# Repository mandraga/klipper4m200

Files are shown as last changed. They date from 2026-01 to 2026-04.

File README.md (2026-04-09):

# klipper4m200

A replacement firmare for the Zortrax M200+ 3D printer.

This firmware is based on Debian/Armbian and allows to install klipper on the m200+.
There is no comming back once the microcontroller is flashed.

# Building steps

Update the submodules, or get them separately.
* Armbian build
* u-boot
* sunxi-tools

## Access the internal single board computer

You need:
* a serial port on the UART0 J5 connector for the u-boot and Linux serial console.
* a special USB-A to USB-A cable with no 5V connexion to be able to use the FEL mode.

At boot, press '2' on the serial console, it will start in FEL mode.
You should see this on "dmesg -w":
```
ID 1f3a:efe8 Allwinner Technology sunxi SoC OTG connector in FEL/flashing mode
```
Then, using sunxi-tools, you can upload a uboot image like this:
```
sunxi-tools$ sudo ./sunxi-fel uboot ../u-boot/u-boot-sunxi-with-spl.bin
```
It starts uboot and you can browse files and dump data.

Then you can use this uboot prompt to load the dtb and the kernel, then boot Armbian from the usb stick.

Once in Linux, you can:
- dump the original disk image on the usb stick.
- dump the vendor u-boot env
- write your u-boot-env
- write u-boot-dtb.bin to the FAT16 partition

## Download the image

Compile u-boot with build_m200.sh from the bootstage folder in this repo, run it in the u-boot fork repo.
Create an Armbian full image using the lime-A33 board using the armbian_build repo.
DD it on /dev/sdx2 where sdx is your usb stick (or edit uboot command to use sdx1 instead).
Do not forget to include linux headers and to enable the touchscreen (see linux.md).
In armbian_build:
```
./compile.sh INSTALL_HEADERS=yes
```

## At first boot from FEL mode

Look at usb.md or progress.md to see how to load the kernel from u-boot.

Install the new u-boot env and mainline uboot binary on the emmc such as to automaticly boot from the USB drive.
The original emmc is not that much altered, only the env. You can resore it with a backup file or in vendor u-boot console.

### Get the network

* On version 2.1, Linux should detect the ethernet usb adapter on the USB port.
  Version 2.1 has two usb ports.
* On version 1.1, the USB0 trace must be cut and a posrt soldered to boot from USB. You need to connect some ethernet 
adapter to an usb hub.
  Version 1.1 has only one USB port on the front.

Then connect your printer to the network.

### Install klipper

Follow this tutorial
https://travis90x.altervista.org/armbian-first-boot-and-install-klipper/

```
git clone https://github.com/dw-0/kiauh.git
./kiauh/kiauh.sh
```
It will install everything klipper related and build the firmware.

### Flash the microcontroller and start Klipper

See the Readme in the MCU folder, you need an ST-Link programmer to mass erase the chip.

## Klipper config

rpanfili has already configured klipper for zortrax M200 but for an SK200 MCU board.
However the geometry and a lot of stock parameters are already in his configuration.

Zortrax has published a Marlin port for the M200.
By looking at the commits, and the work done in the zmxxxp-re repository, I could find the MCU pinouts in "pins_ZORTRAX_M200.h" to configure the klipper MCU firmware.
Be carefull whith the X, Y axis stops, they are not the same depending on verison 1.1 or 2.2.

The configuration in this repo is the rpanfili one, modified for the Zortrax MCU board instead of the SK1.4.

## Calibration and tuning

https://ellis3dp.com/Print-Tuning-Guide/
https://github.com/OrcaSlicer/OrcaSlicer/wiki/Calibration

The ZABS spec
https://cf.zortrax.com/wp-content/uploads/2020/09/Z-ABS_2_Technical_Data_Sheet_eng.pdf

PID tuning at different fan speeds and in GCODE:
https://www.youtube.com/watch?v=USvg6D0cXE4

## Start printing

If everything went fine, you can connect to Mainsail or Fluid web interfaces copy the klipper configuration and start configuring the bed level.
Then, because it is klipper, you must run calibration towers with your filaments and tweak orcaslicer prior to begin printing. That's what's lost in the process but you have control and can use any filament.

## About

This work lasted from october 2025 to April 2026 and was much more difficult than planed, given that the device tree of this thing is really complex, the EMMC is really touchy, and the screen had no driver.
The boot process led to 4 bricks, and needed resoldering a new programmed EMMC to save the boards.
Since then, I tryed to port an ezeetab 96Q10 A-33 Andorid tablet to linux and it was quicker (a week) and also helped to progress on this project.

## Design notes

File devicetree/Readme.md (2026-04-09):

# Mainline linux device tree and u-boot

For the device tree, see git@github.com:mandraga/u-boot.git on the branch zortrax-m200plus.

# Original fex file from the vendor bootloader stage 2

zortraxm200_1.fex is the disassembled version of the printer device description.
Not every voltage regulator in there is found on the board after boot but it was mandatory information to create the linux mainline device tree.

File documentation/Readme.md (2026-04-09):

## Youtube on the open source  Zortrax Marlin port

https://www.youtube.com/watch?v=6i0SUXQyLa4

## Klipper

https://www.youtube.com/watch?v=er7q-CJL1lc
https://mmone.github.io/klipper/Installation.html
https://www.klipper3d.org/Bootloaders.html#stm32f103-micro-controllers-blue-pill-devices
https://github.com/Klipper3d/klipper
https://github.com/Arksine/katapult
https://github.com/dw-0/kiauh

## MarlinZortrax

https://github.com/Zortrax3D/MarlinZortraxM200

## eevblog topic on klipper for zortrax

https://www.eevblog.com/forum/3d-printing/hack-zortrax-driver-board-port-klipper/

https://github.com/zharijs/zmxxxp-re

## Zortrax is cooked but still alive

https://forum.zortrax.com/t/m200-m300-marlin-2-1-x-firmware-release/14264/38

### Total conversion

https://github.com/rpanfili/sk200

## A33 sunxi ressources

### Machine alike

https://linux-sunxi.org/Sinlinx_SinA33
Nearly the same, when looked from a distance.

## Zortrax Machine

* A33
* 1GB DDR3
* 8GB EMMC
* 2 usb ports
* UART0 J5 console port (molex)
* HOME/FEL mode button (only for android)

Pinout in A33-core3.pdf
Adafruit SSDIO breakout board:
https://www.adafruit.com/product/4682

### Connector

C'est du Molex.

### Flash methods

https://docs.u-boot.org/en/latest/board/allwinner/sunxi.html

### FEL flash method
https://linux-sunxi.org/FEL

### UBoot
https://github.com/u-boot/u-boot/blob/master/doc/board/allwinner/sunxi.rst

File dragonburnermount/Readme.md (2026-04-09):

# Adapting a Dragon burner head to the zortrax m200

## Why?

* Your heater element is broken or missing
* You want more up to date tech
* You bough a Zortrax M200 or M300 without heating element.

## How?

* Print an adapter
  Use the dragon burner configurator https://dragonburner.voron.zip/DragonBurnerConfig/#/
* Chose your heat element
* Solder the fan cables to extend them (maybe you can reuse the heater element fan)
* Change the thermistor for a themocouple (like 1188-TC-K-TYPE-ND form Olimex)

## What heat element?

I chose a Rapido and a TZ-V6-2. But you have to solder things and it is anoying.
The best choice would be a Phaetus Dragon hotend because you do not change the heating elements
nor the thermocouple. And with a bit of luck with the fans cable length, you do not have to solder.

### Phaetus Rapido

And download the main body and the rapido adapter.
Instead of an extruder mount, print dragonburnermountonM200_B.stl
You need 35mm 5mm/6mm M3 screws (flat head for the 6mm long screw).
Replace the thermistor with a thermocouple.

### Triangle labs TZ-V6-2

This one is not really suported by the dragon burner project.
You need 35mm 5mm/6mm M3 screws (flat head for the 6mm long screw).
Replace the thermistor with a thermocouple.
Print the main fan body and this adapter:
https://www.printables.com/model/1292661-dragonburner-tz-v6-20-mount-with-v6-nozzle
Add washers on the support because the heater wobbles.
Change the nozzle to a V6 because the default nozzle is not made for that mount.
It will be at blower level and won't work.

### Dragon hotend

Not tested, but should be the simplest. Using the original heater and thermocouple even if the wire are a bit short. It is the first choice for the Dragon burner and it is afordable.
You need 35mm or 5mm/6mm M3 screws (flat head for the 6mm long screw).

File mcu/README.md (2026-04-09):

## MCU compilation for the MCU board

The MCU is a STM32F103VC on the M200 and the stepper motor drivers are A4988.
Format LQFP100

STM32F103VC
Flash memory: 256KB
SRAM: 64 KB
Package: LQFP100

### From the Marlin port

```
#
# Zortrax M200/M300 (STM32F103VCT6)
#
[env:STM32F103VC_zortrax_m200]
extends                     = stm32_variant
board                       = genericSTM32F103VC
board_build.variant         = MARLIN_F103Vx
build_flags                 = ${stm32_variant.build_flags} -DDEBUG_LEVEL=0
monitor_speed               = 115200
board_build.offset          = 0x8000       (32768 bytes, 32K offset)
board_upload.offset_address = 0x08008000
```
However, their bootloader is undocumented and the data seems encrypted because firmware.bin does not contian arm code.
It can be replaced by Katapult, using the debug pins.

### Build the firmware

```
./kiauh/kiauh.sh
Select
 4) [Advanced] 
  1) [Build] 
```

And then select (Enable extra low-level configuration options):
Micro-controller Architecture: STM32
Processor model:               STM32F103
Bootloader at:                 8K for katapult, 32K if it was the zortrax bootloader (and it is not).
Communication interface:       USART2 on PA3 PA2
Frequency                      8Mhz

It will build the firmware.

### Configure

The firmware is generic, it needs a configuration file to assign the pins and other stuff.
The configuration can be deduced from the Zortrax Marlin port. See in "pins_ZORTRAX_M200.h".

The other part of the work for the printer configuration has been made by rpanfili in his sk200 retrofit.
He used an sk200 and he changed the stepper motors and mybe the extruder but the other parts are the same.

#### Serial communication

To connect serial user interface (OctoPrint or other using Raspberry PI or UART converter and PC) you can use debug header on the motherboard. You will need to solder connector by yourself.

Pinout of the **DEBUG** header described below:
-	NRST
-	**GND <--- connect to GND on host**
-	TMS/NC SWDIO
-	TCK/NC SWDCLK
-	**TX <--- connect to RX on host**
-	**RX <--- connect to TX on host**
-	BOOT0
-	VCC (marked on mainboard as 3.3V)

**Caution**: if you are going to use debugger (ST-Link), know that any attempt to read or write from/to flash memory will result in mass erase of the flash. It will erase the the bootloader and all the settings, including lifetimer, serial number and hardware version, as flash memory of chip is read out protection enabled at production! If that happens you won't be able to use official firmware anymore!

### Android board P3 Pins

Android side       MCU side

5V                 5V
GND                GND
GPIO               STM
ADOHC              MTS
LED                BOOT
GPIOS              GPIO
RST                RST
SLP
RX                 RX
TX                 TX

      MCU Pins                              Android pins
-------------------------------------------------------------------------------------------------
STM   is PD2 TIM3_ETR/UART5_RX/SDIO_CMD     gpio_pin_5 = port:PC01<1><default><default><0>  MISO
MTS   is PD1 OSC_OUT/FSMC_D3/CAN_TX         gpio_pin_6 = port:PC00<1><default><default><0>  MOSI
BOOT  is PD3 USART2_CTS                     gpio_pin_7 = port:PC02<1><default><default><1>  CLK
GPIO  is PD5 USART2_TX                      gpio_pin_8 = port:PC03<0><1><default><0>        CS
RESET is PD4 USART2_RTS                     gpio_pin_9 = port:PF01<1><default><default><0>  
SLP   is not connected                      gpio_pin_10 = port:PF00<1><default><default><0>
RX    is PA3 USART2_RX                      PB0
TX    is PA2 USART2_TX                      PB1

uart2_cts_rts_pb_pins: uart2-cts-rts-pb-pins {
    pins = "PB2", "PB3";
    function = "uart2";
};

## Debug connector:

RESET; VSS/GND; PA13;     PA14;        PA10;       PA9;      BOOT0; 3.3V
              JTMS-SWDIO  JTCK-SWCLK  USART1_RX  USART1_TX
                                           
                                           STLINK
1 3.3V (square pin)                     1 3.3V (square pin)    X
2 BOOT0                                 2 SWCLK                to 5
3 PA9      USART1_TX                    3 GND                  to 7
4 PA10     USART1_RX                    4 SWDIO                to 6
5 PA14     JTCK-SWCLK                   5 RESET                to 8
6 PA13     JTMS-SWDIO                   6 SWO                  X
7 VSS/GND
8 RESET

### Katapult configuration

Replacing the vendor bootloader with the katapult bootloader using the debug port.

To configure the Katapult bootloader. From the katapult repo: use the following `make menuconfig` options.

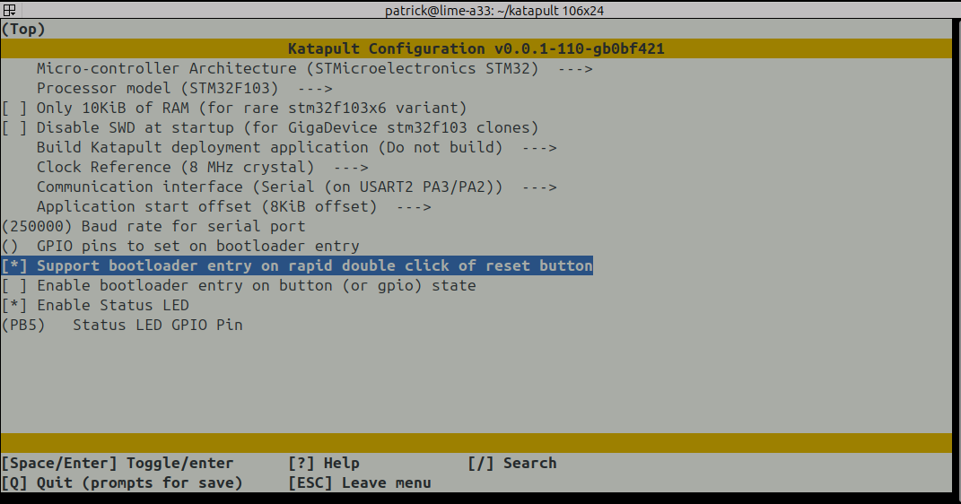
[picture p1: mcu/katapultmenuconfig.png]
Katapult Menuconfig


In the Katapult repo:
```
make menuconfig

Micro-controller architecture: STM32F13
No deployment application
Clock reference: 8Mhz crystal
Communicaiton iunterface: USART2 PA3/PA2
Application start offset 8KB offset.

make
```

It generates ./out/katapult.bin
That's what we flash as bootloader.
Using the Katapult's flashtool on the debug header. This erases the chip and there is no coming back to the Zortrax firmware and software suite.
The stock MCU is read protected, we must do a mass erase prior to flashing Katapult.
An uart is not enough, we need the SWDIO SWDCLK pins connected to a STLINK V2 system.

```
$ sudo apt update
$ sudo apt install stlink-tools openocd

# Unlock the chip with open ocd
# Start openocd
$ openocd -f interface/stlink.cfg -f target/stm32f1x.cfg

# In another console:
$ telnet localhost 4444
Trying 127.0.0.1...
Connected to localhost.
Escape character is '^]'.
Open On-Chip Debugger
> reset halt
[stm32f1x.cpu] halted due to debug-request, current mode: Thread 
xPSR: 0x01000000 pc: 0xfffffffe msp: 0xfffffffc
> stm32f1x unlock 0
device id = 0x10036414
STM32 flash size failed, probe inaccurate - assuming 512k flash
flash size = 512 KiB
stm32x unlocked.
INFO: a reset or power cycle is required for the new settings to take effect.

> shutdown
shutdown command invoked
Connection closed by foreign host.
```
Then reset the chip and use st-flash to finish the job.
```
$ st-info --probe

Found 1 stlink programmers
  version:    V2J16
  serial:     303030303030303030303031
  flash:      262144 (pagesize: 2048)
  sram:       65536
  chipid:     0x414
  dev-type:   F1xx_HD

$ st-flash erase
st-flash 1.8.0
2026-01-23T23:15:39 INFO common.c: F1xx_HD: 64 KiB SRAM, 24544 KiB flash in at least 2 KiB pages.
Mass erasing...
Mass erase completed successfully.

$ st-flash write ./out/katapult.bin 0x8000000

st-flash 1.8.0
2026-01-23T23:28:59 INFO common.c: F1xx_HD: 64 KiB SRAM, 256 KiB flash in at least 2 KiB pages.
file ./out/katapult.bin md5 checksum: 3f9582c8e129668f7be5ef1487634c7, stlink checksum: 0x0004b37d
2026-01-23T23:28:59 INFO common_flash.c: Attempting to write 3348 (0xd14) bytes to stm32 address: 134217728 (0x8000000)
-> Flash page at 0x8000800 erased (size: 0x800)
2026-01-23T23:28:59 INFO flash_loader.c: Starting Flash write for VL/F0/F3/F1_XL
2026-01-23T23:28:59 INFO flash_loader.c: Successfully loaded flash loader in sram
2026-01-23T23:28:59 INFO flash_loader.c: Clear DFSR
2026-01-23T23:28:59 INFO flash_loader.c: Clear CFSR
2026-01-23T23:28:59 INFO flash_loader.c: Clear HFSR
  2/2   pages written
2026-01-23T23:28:59 INFO common_flash.c: Starting verification of write complete
2026-01-23T23:28:59 INFO common_flash.c: Flash written and verified! jolly good!
```

STM32Programmer can also be used to the same goal.

### Flashing the klipper software

Now from the single board computer.

To configure the Klipper firmware, you can use the following `make menuconfig` options from the klipper repo. Refer to the image below for guidance:

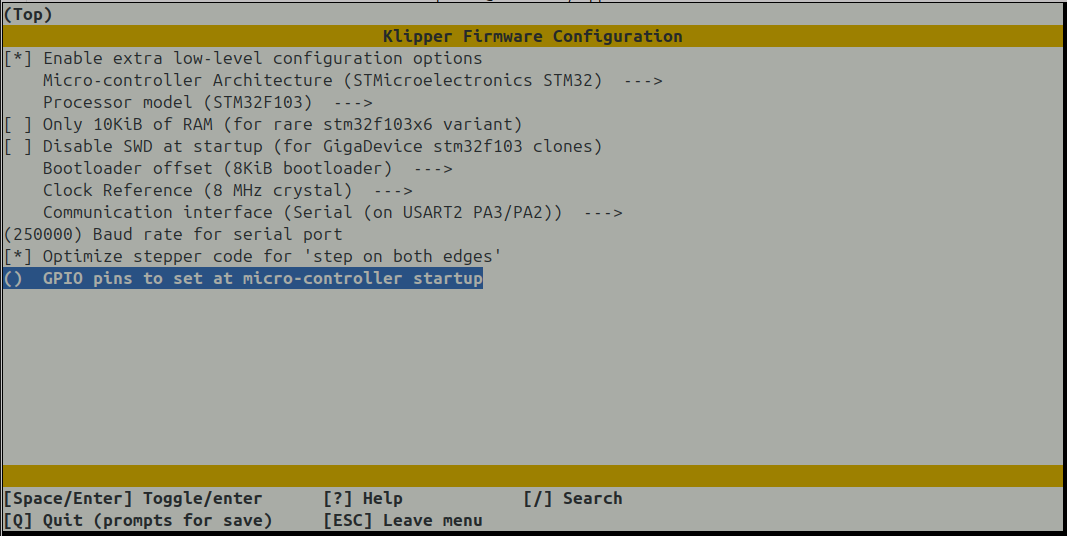
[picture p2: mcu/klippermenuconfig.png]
Klipper Menuconfig


Make sure to select the appropriate options for your setup.
```
make menuconfig
make

~$ sudo apt update
~$ sudo apt install python3-serial
~$ sudo service klipper stop
# Reset the device with the debug port
~$ sudo python3 ./katapult/scripts/flashtool.py -d /dev/ttyS2 -b 250000 -f ./klipper/out/klipper.bin
Connecting to Serial Device /dev/ttyS2, baud 250000
Detected Klipper binary version v0.13.0-464-g48f0b3ca, MCU: stm32f103xe
Attempting to connect to bootloader
Katapult Connected
Software Version: v0.0.1-110-gb0bf421
Protocol Version: 1.1.0
Block Size: 64 bytes
Application Start: 0x8002000
MCU type: stm32f103xe
Flashing '/home/patrick/klipper/out/klipper.bin'...

[##################################################]

Write complete: 19 pages
Verifying (block count = 581)...

[##################################################]

Verification Complete: SHA = 937D058BE91B1866070F106B6476898C47725810
Programming Complete
```

### Update the firmware using the bootloader

Once klipper installed with the STM32 programmer, we can update the firmware using the serial port.
If fuser of the Klipper serial port returns something, then stop the Klipper service.
```
fuser /dev/ttyS2
/dev/ttyS2:            946
sudo service klipper stop
# Reset the mcu board using the debug port
sudo python3 ./katapult/scripts/flashtool.py -d /dev/ttyS2 -b 250000 -f ./klipper/out/klipper.bin
sudo service klipper start
```

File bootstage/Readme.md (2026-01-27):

Find a compatible u-boot here: git@github.com:mandraga/u-boot.git
The device tree is in this repository.
It is also in the submodules.

The modified u-boot env replaces the stock env, it adds a one second wait to enter the u-boot console instead of zero, and chain loads u-boot mainline as default boot command.

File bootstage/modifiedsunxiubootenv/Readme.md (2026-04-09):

## Env to chainload u-boot

This env image for sunxi secondary loader chainloads u-boot from the FAT16 partition.
To install it from Armbian:

```
dd if=sunxi_env.img of=/dev/mmcblk2p5
```

And copy u-boot proper to mmcblk2p2:

```
cd /mnt/
mkdir -p /mnt/ext4disk
mkdir -p /mnt/fat16disk
mount /dev/sda1 ext4disk/
mount /dev/mmcblk2p2 fat16disk
cp ext4disk/u-boot-dtb.bin fat16disk/
sync
reboot
```

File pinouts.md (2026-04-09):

## P3 Single Board Computer to Micro Controller Unit

It goes through a level shifter, and the labels are obfuscated.

1  TX
2  RX
3  SLP
4  RST
5  GPIOS
6  LED
7  ADOHC
8  GPIO
9  GND
10 5V

## SDIO

The first SD card slots is not populated. 
SDIO_0 has no traces outside of the SOM board, SDIO_1 goes to an unpopulated SDWifi chip..
A test to use it with a card did not work.

## LED

Two onboard leds. Only the power led does something below the power button.
BTW the power button is more of a reset button.

## USB

Both usb are used.
USB1 on J4
USB0/OTG on P4

## Ethernet

On rev1 we have a soldered realtek ehternet chip. We cut it out in order to solder an usb hub.
On rev2 we have an USB2.0 Hub and the realtek ehternet chip is there. No need to cut or solder anything.

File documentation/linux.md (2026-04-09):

## Menuconfig the kernel compilation.

In the armbian image repository (https://github.com/armbian/build.git)

./compile.sh INSTALL_HEADERS=yes
and chose to show a menuconfig

Configure to use the lime A33 system.

## Touch screen information

https://forum.armbian.com/topic/7233-bananapi-pro-7-touchlcd-with-debian-buster-and-mainline-kernel-5xxxx/

## LCD information

The screen is a "MTF0397SWI-06"
IC: OTM8019A
Sunxi driver: sl698ph_720p
We also find the name hx8394d in the driver functions.
Himax HX8394 is the mainline driver name for hx8394d, looks like the sunxi driver, same command codes but different data sizes in the two drivers.

In the sl698ph_720p driver it takes hx8394d or otm1283 depending on the identification result.

On a boot parition, we find lcd.ko containing sl698ph_720p but also lp079x01.
lp079x01 is an LG display.
The driver has been compiled with debug information. "otm1283_initialization_setting" apears in the debug info.
So we have the driver source code, we need to adapt it to mainline linux.

We find lcd names: tft720x1280 vvx10f004b00 lp907qx starry768x1024

Acording to the debug info, the lcd module includes sl698ph_720p.c. However his initialisation data is not the same as in the public sunxi driver, it must be extracted from the module on the printer.

# Possible modern drivers to be used as "donor" structure

https://github.com/l33tnoob/tinno82_S5501/blob/master/mediatek/custom/common/kernel/lcm/otm1283a_hd720_dsi_vdo/otm1283a_hd720_dsi_vdo.c

The term "LCM" (Liquid Crystal Module drivers) is commonly used in MediaTek and some Allwinner/Android vendor kernels. You’ll often see files named like otm1283a_hd720_dsi_vdo.c or hx8394d_dsi_vdo.c in directories such as kernel/lcm/ or kernel/drivers/lcd/. LCM drivers are a vendor-specific concept and are not part of mainline Linux. Mainline Linux uses the DRM/KMS subsystem and expects panel drivers to implement the struct drm_panel interface.

We take the closest mainline driver from the Armbian sources.

# Writing the driver

We take the panel-himax-hx8394.c file structure and use the pannel init from "otm1283_initialization_setting" in sl698ph_720p.c with the data extracted from the lcd kernel module on the printer.

### LCD pannel driver compilation

To compile panel-mtf0397swi.c as a kernel driver for Armbian, you need to integrate it into the kernel source tree and build it as part of the kernel or as a loadable module. 

https://www.kernel.org/doc/html/latest/kbuild/modules.html

Compilation. A Makefile with only "obj-m += panel-mtf0397swi.o" is enough.

```
scp -o IdentitiesOnly=yes panel-mtf0397swi.c root@192.168.1.158:/home/user/lcd_driver
echo "obj-m += panel-mtf0397swi.o" > Makefile
make -C /lib/modules/`uname -r`/build M=$PWD
```

Installation

```
sudo cp panel-mtf0397swi.ko /lib/modules/$(uname -r)/kernel/drivers/gpu/drm/panel/
sudo depmod -a
sudo modprobe panel-mtf0397swi
```

### Testing the screen

```
dmesg | grep drm
dmesg | grep dsi
```
bootdelay
bootdelay
```
# This reload my be needed on the nearly working version.
sudo modprobe -r panel-mtf0397swi
sudo modprobe panel-mtf0397swi

modetest -c

apt update && sudo apt install libdrm-tests mesa-utils kmscube
kmscube

# Display a 800x600 image (stop klipperscreen if installed: "sudo systemctl stop KlipperScreen")
sudo apt install fbi
fbi -T 1 -d /dev/fb0 -a ../OIP-2008394785.jpeg 
```

 ### Rotate the screen for KlipperScreen

```
sudo nano /etc/X11/xorg.conf.d/01-armbian-defaults.conf 
```
Put this in the file:
```
Section "Monitor"
    Identifier "DSI-1"
    Option "Rotate" "left"
EndSection
```

Restart KlipperScreeen
```
sudo systemctl restart KlipperScreen
```

## Compilation

Go to the armbian build repo and call "./compile.sh INSTALL_HEADERS=yes", then select kernel compilation.
TODO: add the zortrax to armbian "at your own risk" boards
Select current kernel with:

### Touchscreen
- touch screen in 
Device Drivers --->
    Input device support --->
        Touchscreens --->
            EDT FocalTech FT5x06 I2C Touchscreen support"

CONFIG_TOUCHSCREEN_EDT_FT5X06

#### If it fails for the touchscreen
Once, the compilation worked but it dit not pack the module on the image.
In that case, coopy the source from the Armbian build cache and compile on the target:

```
echo "obj-m += edt-ft5x06.o" > Makefile
make -C /lib/modules/`uname -r`/build M=$PWD
cp edt-ft5x06.ko /lib/modules/$(uname -r)/kernel/drivers/input/touchscreen/
depmod -a
```

## LCD

You will need to compile the lcd driver for your armbian, using the armbian_build git repository.

### Compilation on the target

Assuming the image has the headers.
./compile.sh INSTALL_HEADERS=yes

### Cross compilation with the armbian build kernel source

make
and then copy on the system

Copy in
/lib/modules/6.12.51-current-sunxi/kernel/drivers/

Does not work because of some timestamp anf debug info not matching the image

### Inserting the module code in the source

sudo cp panel-mtf0397swi.c /home/patrick/moredata/emmc/armbian_build/cache/sources/linux-kernel-worktree/6.12__sunxi__armhf/drivers/gpu/drm/panel

sudo nano Kconfig

config DRM_PANEL_MTF0397SWI
        tristate "Microtech Technology MTF0397SWI-06 panel"
        depends on OF
        depends on DRM_MIPI_DSI
        depends on BACKLIGHT_CLASS_DEVICE
        help
          Say Y here if you want to enable support for Microtech Technology MTF0397SWI panel.

sudo nano Makefile

obj-$(CONFIG_DRM_PANEL_ABT_Y030XX067A) += panel-mtf0397swi.c.o

Then run

export CROSS_COMPILE=arm-linux-gnueabihf-
make ARCH=arm zImage -j$(nproc)
make ARCH=arm modules -j$(nproc)
This does not work, it must be armbian specific stuff

Trying with the config thing

### With compile.sh

https://docs.armbian.com/Developer-Guide_Build-Switches/

./compile.sh INSTALL_HEADERS=yes

Then on the device the headers are in

/usr/src/linux-headers-6.12.51-current-sunxi/

https://forum.armbian.com/topic/6-how-to-build-my-own-image-or-kernel/

### Compiling on the system

scp panel-mtf0397swi.c  

https://www.kernel.org/doc/html/latest/kbuild/modules.html
```
echo "obj-m += panel-mtf0397swi.o" > Makefile
```

From the driver soure directory:

```
make -C /lib/modules/$(uname -r)/build M=$PWD
```

Using bleeding edge 6.16 kernel is a bad idea, cmpilation does not work, and many errors in dmesg.

./compile.sh kernel BOARD=lime-a33 BRANCH=current RELEASE=trixie BUILD_MINIMAL=yes SOURCE_COMPILE="yes" 

### Testing the touchscreen

```
sudo apt update
sudo apt install -y evtest evemu-tools libinput-tools i2c-tools
evtest
```

### Check the device tree

```
dtc -I fs /proc/device-tree | sed -n '/panel@/,/};/p' 
```

### Camera

It is a GalaxyCore GC2145 2MP sensor
Already enabled CONFIG_VIDEO_GC2145=m
But the csi driver seems not to be compatible and the i2cdetect gives nothing.
Maybe an enable pin problem.
So for now it stays deactivated.

Drivers on the vendor system:

./vendor/modules/gc0307.ko
./vendor/modules/gc0308.ko
./vendor/modules/gc0309.ko
./vendor/modules/gc0311.ko
./vendor/modules/gc0328.ko
./vendor/modules/gc0329.ko
./vendor/modules/gc2035.ko
./vendor/modules/gc2155.ko
./vendor/modules/gc5004.ko
./vendor/modules/gc5004_mipi.ko

./vendor/modules/ov12830.ko
./vendor/modules/ov13850.ko
./vendor/modules/ov16825.ko
./vendor/modules/ov2640.ko
./vendor/modules/ov5640.ko
./vendor/modules/ov5647.ko
./vendor/modules/ov5647_mipi.ko
./vendor/modules/ov5648.ko
./vendor/modules/ov5650.ko
./vendor/modules/ov7736.ko
./vendor/modules/ov8825.ko
./vendor/modules/ov8825_act.ko
./vendor/modules/ov8850.ko
./vendor/modules/ov8858.ko
./vendor/modules/ov8858_4lane.ko

#### Installation

We place the module in the image, and add compatible "MTF0397SWI-06, sl698ph_720p" to the device tree pannel object.

### Wifi

It is a rtl8188eu if we look at the logs but AP6210 on the board.

### Wifi

Linux Kernel Configuration  
└─>Device Drivers  
    └─>Network device support  
        └─>Wireless LAN  
            └─>Realtek RTL8188EU Wireless LAN NIC driver

Could also be a RTL8723BS
Linux Kernel Configuration
└─>Device Drivers
    └─>Staging drivers
        └─>Wireless LAN
            └─>MMC/SD/SDIO card support
                └─>Realtek RTL8723BS SDIO Wireless LAN NIC driver 

```
[    0.668179] [wifi]: select wifi: rtl8188eu !!
[    0.668426] [rtl8188eu]: exec rtl8188eu_wifi_gpio_init
[    0.668442] [rtl8188eu]: module power name axp22_dldo1
[    0.668453] [rtl8188eu]: module power ext1 name 
[    0.668463] [rtl8188eu]: module power ext2 name 
[    0.668474] [rtl8188eu]: rtl8188eu module power set by axp.
[    0.668611] [rtl8188eu]: get power regulator  failed.
[    0.668623] [rtl8188eu]: first time
[    0.668846] [wifi_pm]: wifi gpio init is OK !!

```

It can work in USB mode, or use the SDIO + uart interface. The usb wifi shipped on the m200+ rev 2.1 is also a RTL8188EU. The module is rtl8xxxu.

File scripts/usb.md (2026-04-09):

## UMS mode

Uboot has a UMS mode such as the emmc becomes a usb mass storage device. But I could not make it work on the m200. The command was not visible and, if the otg was enabled in the device tree, uboot crashed.
Plus the USB0 port has weird settings with a regulator at 3V (see the fex file). And VBUS on the OTG port is enabled through a pin enable.

## Transfering an image without usb

Until the UMS mode works, we can use scripts to break the image into 16MB files and load them one by one from a memory stick to the EMMC1 using the serial port to do the reassembling.

## Transfer using linux

We can boot an image from the usb drive and use this image to flash the device.
From the zortrax single board computer:

```
setenv bootargs root=/dev/sda1 rootwait console=ttyS0,115200  rw
usb start
fatload usb 0:1 0x42000000 zImage
fatload usb 0:1 0x43000000 sun8i-a33-zortrax-m200plus.dtb
bootz 0x42000000 - 0x43000000
```

```
setenv bootargs root=/dev/sda2 rootwait console=ttyS0,115200  rw
usb start
ext4load usb 0:1 0x42000000 zImage
ext4load usb 0:1 0x43000000 sun8i-a33-zortrax-m200plus.dtb
bootz 0x42000000 - 0x43000000
```

Login and then dump the firmware on a USB drive

```
cd /mnt
mkdir ext4disk
mount /dev/sda3 ext4disk/
dd if=/dev/mmcblk2 of=ext4disk/emmc.image bs=4M status=progress
sync
poweroff
```

## The Android system image
```
mount /dev/mmcblk2p7 system/
```

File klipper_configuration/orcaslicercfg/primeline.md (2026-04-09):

### Prime line to begin extrusion before the printed object

```
; Prime line BEGIN
G1 X2.0 Y2.0 F18000 ; Move to edge of bed
G1 Z0.2 F5000 ; Lower nozzle
G92 E0.0 ; Reset extruder position
G1 X200.0 E32.0 F1000.0 ; Start intro line
G1 X2.0 Y2.24 F18000 ; Move out of the first line
G1 X50.0 E14.0 F1000.0 ; Finish thicker line
G92 E0.0 ; Reset extruder position again
; Prime line END
```

### Start code

Just homing, then add the prime line after the temperature is stable.

```
G28
```

### End code

Home and stop the heaters.
Boost the fans for a couple seconds?
Emit a sound using the Z axis ?

```
PRINT_END
G28
M104 S0
M140 S0
```

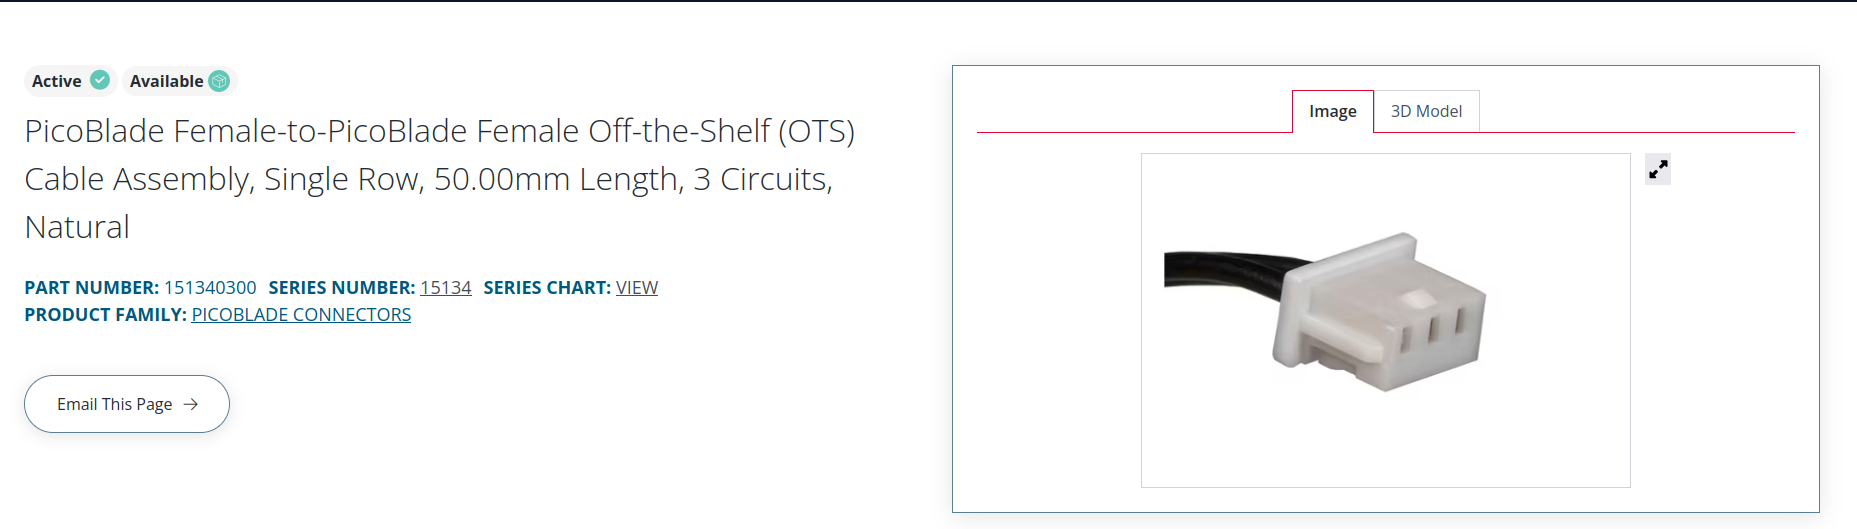
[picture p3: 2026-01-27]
pcb/usb_uart_m200/doc/MolexPicoBlade.png

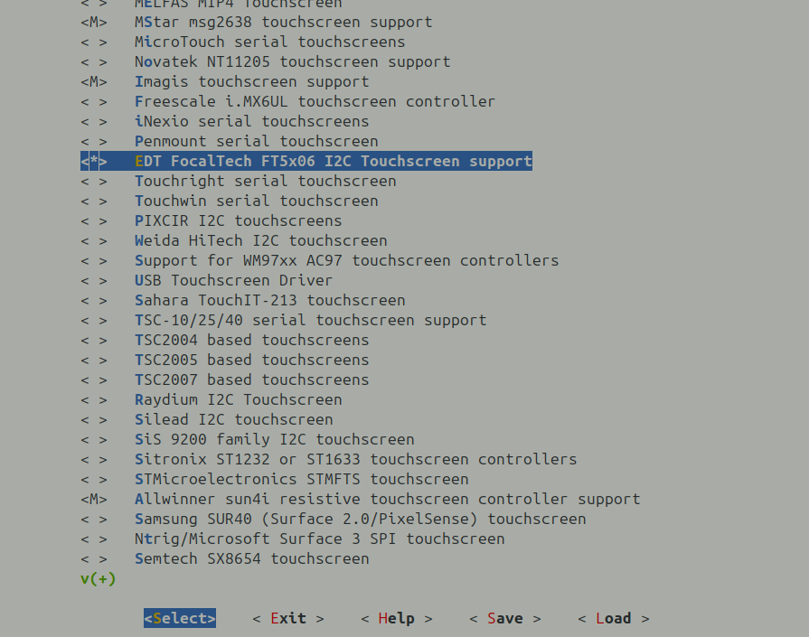
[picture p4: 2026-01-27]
documentation/kernel_config_EDT_FocaltehcTouchscreen.png

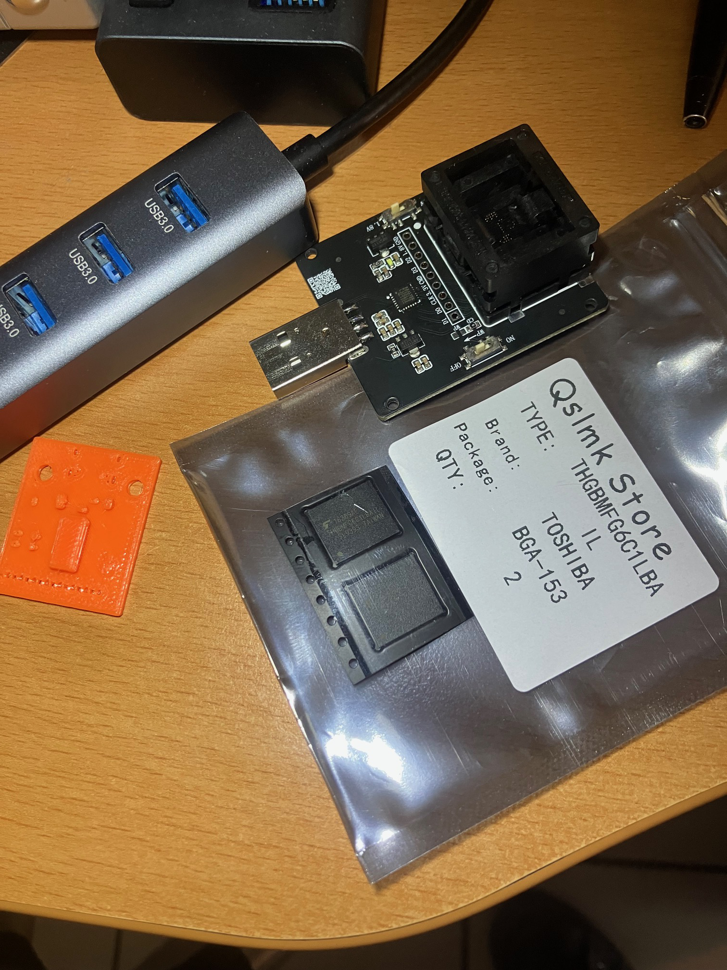
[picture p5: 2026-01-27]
documentation/emmc_for_m200plus_unbricking.jpg

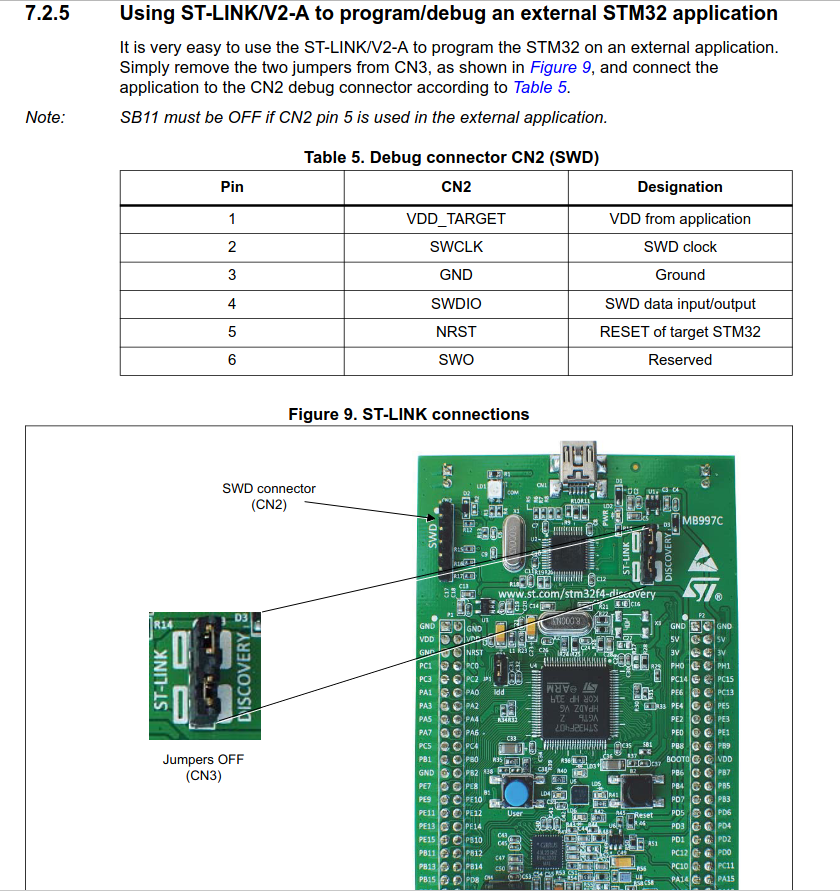
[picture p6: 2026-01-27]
mcu/STM_discovery_STLINK.png

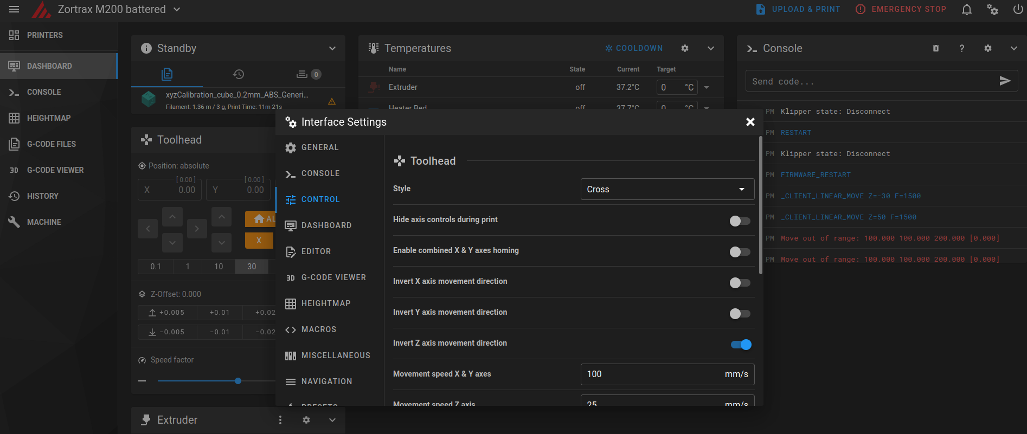
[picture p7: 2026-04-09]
documentation/mainsal_invert Zaxis_direction.png

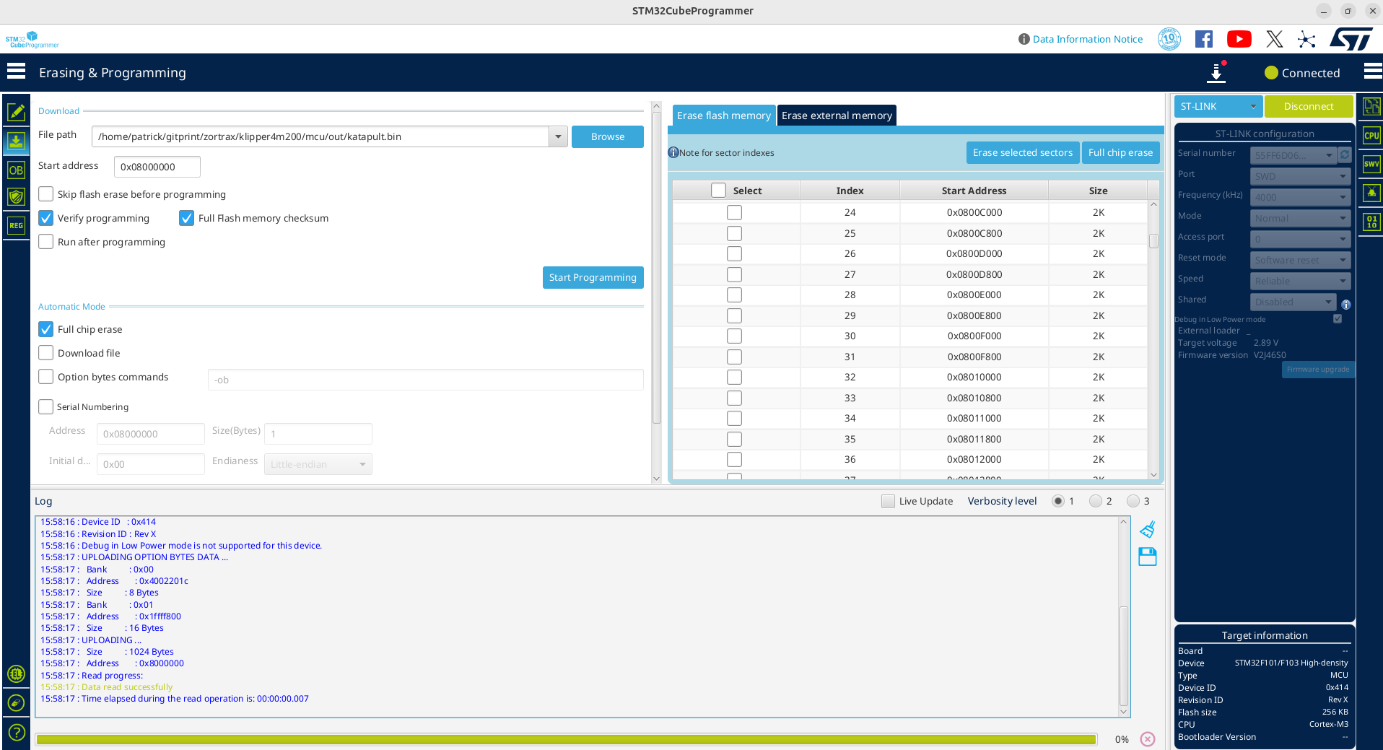
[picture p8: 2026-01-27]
mcu/STM32CubeProgrammer.png

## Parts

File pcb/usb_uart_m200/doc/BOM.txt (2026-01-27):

Ground connector wire Farnell code 3226691

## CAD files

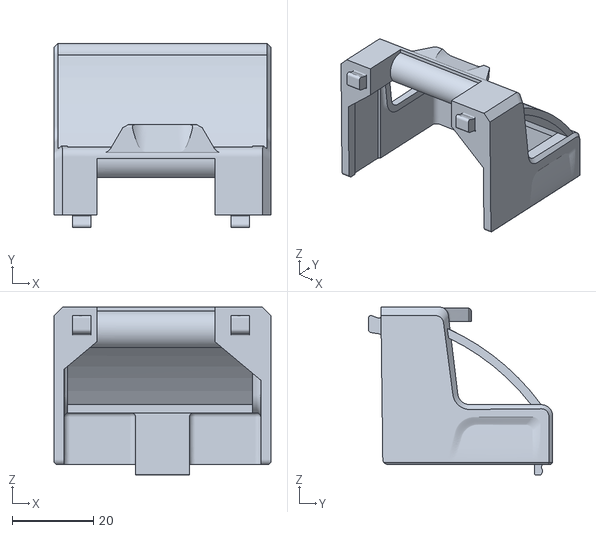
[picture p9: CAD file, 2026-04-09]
dragonburnermount/extrudercoverbackwithmorespace.stl
53.4 x 45.4 x 41.3

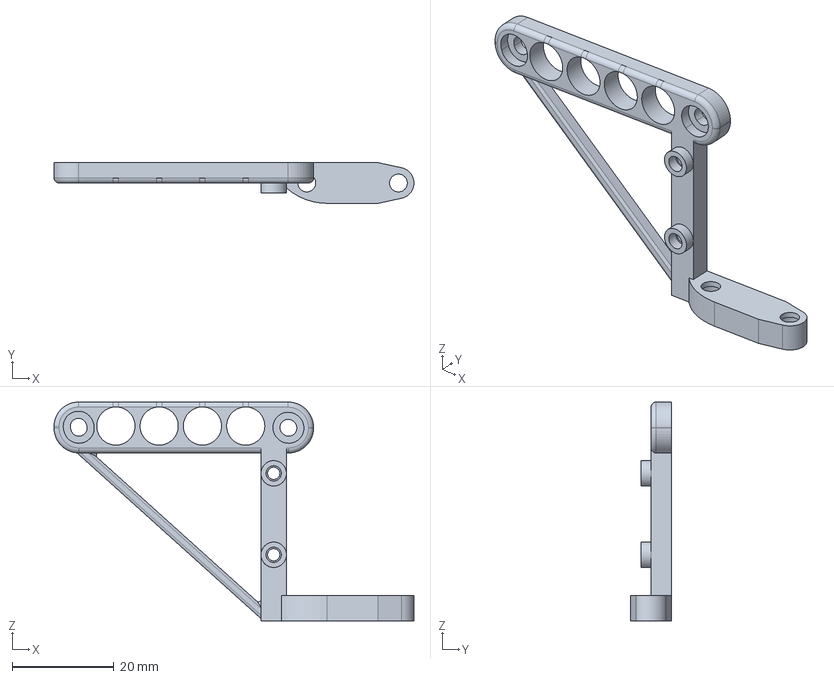
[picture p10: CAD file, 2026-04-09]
dragonburnermount/bltouchmount.FCStd
70.7 x 8.00 x 43.0 mm

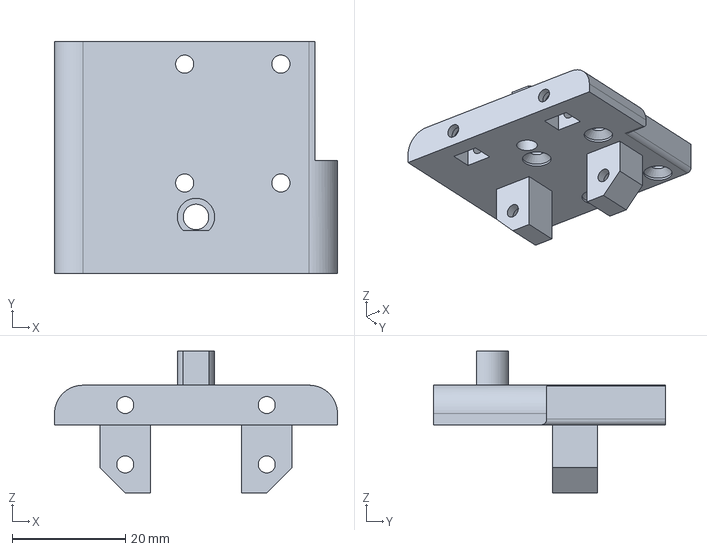
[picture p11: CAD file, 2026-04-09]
dragonburnermount/dragonburnermountonM200_B.FCStd
50.0 x 41.0 x 25.0 mm

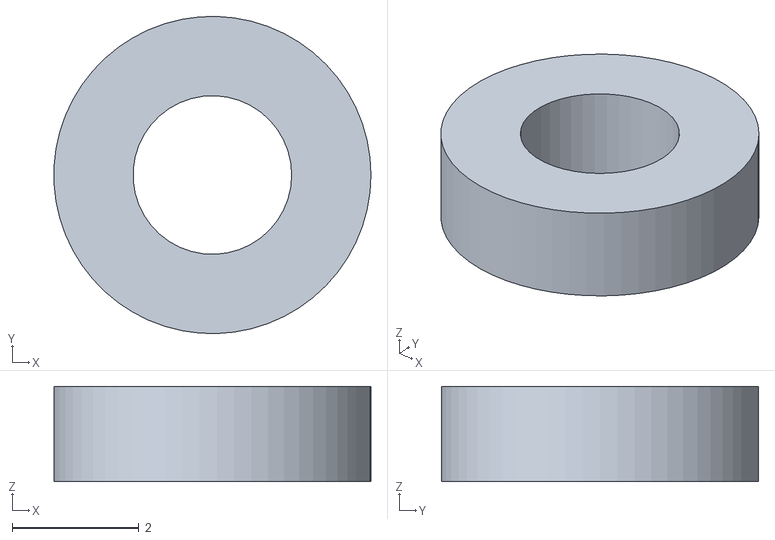
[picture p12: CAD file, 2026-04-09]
dragonburnermount/washerforTZ-6-V2.stl
5.00 x 5.00 x 1.50

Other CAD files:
dragonburnermount/washerforTZ-V6-2.FCStd
dragonburnermount/bltouchmount.stl
dragonburnermount/dragonburnermountonM200_B.stl

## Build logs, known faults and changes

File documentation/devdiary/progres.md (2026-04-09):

## Access

- Console is on ART0 -> pressing '2' at start enables FEL mode
- USB0 on P4 is the OTG port -> it allows FEL mode procotol

## Andoid debug

Pressing HOME at start loads the Android Debug Mode port, however, the USB device
is not enabled. So no  ADB.

## Reading the content

The FEL mode is the protected mmcblk2Boot0 EMMC partition.
It allows to load a FES image, do not touch it. Any error will brick the device (unless you can solder a new programmed EMMC).

On the Zortrax, the Allwinner bootloader first looks for FEL mode, then locates SDcard 0 (non existent) and the EMMC2.
Then it loads UBoot.
Uboot cannot be stopped to use it to scan the partitions as his bootdelay is 0.
Uboot loads the linux Kernel.

On FEL mode from a remote console, we can only read the RAM.

## Machine

Machine: sun8i
Linux version 3.4.39 

### FEL 

./sunxi-fel -l
USB device 003:011   Allwinner A33     0461872a:890c2042:ab98b7e7:00000000

### A33 sun8i machines

#### Tablets
Allwinner GA10H Quad Core Tablet (v1.1) sun8i-a33-ga10h-v1.1.dtb
ET Q8 Quad Core Tablet (v1.6)	        sun8i-a33-et-q8-v1.6.dtb
INet-D978 Rev 02	                    sun8i-a33-inet-d978-rev2.dtb
Q8 A33 Tablet	                        sun8i-a33-ippo-q8h-v1.2.dtb
Q8 A33 Tablet	                        sun8i-a33-q8-tablet.dtb

#### Single board computers (very similar)
Olimex A33-OLinuXino	                sun8i-a33-olinuxino.dtb
Sinlinx SinA33	                        sun8i-a33-sinlinx-sina33.dtb    1GB DDR3 、4GB EMMC

## FEX files

A usefull commented fex file is here:
https://github.com/linux-sunxi/sunxi-boards/blob/master/sys_config/a33/sinlinx_sina33.fex

## Compiling a Uboot SPL

I try to compile uboot with A33-OLinuXino_defconfig and use sun8i-a33-olinuxino.dtb

```
make CROSS_COMPILE=arm-linux-gnueabihf- A33-OLinuXino_defconfig
make CROSS_COMPILE=arm-linux-gnueabihf- -j$(nproc)

sudo ./sunxi-fel uboot u-boot-sunxi-with-spl.bin
```

```
early jump fel

U-Boot SPL 2025.10-rc5 (Oct 19 2025 - 13:51:27 +0200)
DRAM: 1024 MiB
Trying to boot from FEL

U-Boot 2025.10-rc5 (Oct 19 2025 - 13:51:27 +0200) Allwinner Technology

CPU:   Allwinner A33 (SUN8I 1667)
Model: Olimex A33-OLinuXino
DRAM:  1 GiB
Core:  60 devices, 21 uclasses, devicetree: separate
WDT:   Not starting watchdog@1c20ca0
MMC:   
```

Hangs at MMC, so not the proper MMC adress.
Recreating a temporary dts, the MMC is not found, hence it will be a problem.

UBoot for sinlinx A33 does not help

## EMMC ports

SDIO0 is used for the unpopulated U5 wifi chip.
SDIO1 is also left hanging.
And the chip uses and only boots on SDIO2/MMC2.
- In 4 bit mode for UBoot, and double speed mode for linux.

### PMIC

axp22_board axp22_board: AXP (CHIP ID: 0x06) detected
axp22_dcdc1: 1600 <--> 3400 mV at 3000 mV 
axp22_dcdc2: 600 <--> 1540 mV at 1100 mV 
axp22_dcdc3: 600 <--> 1860 mV at 1200 mV 
axp22_dcdc4: 600 <--> 1540 mV at 1100 mV 
axp22_dcdc5: 1000 <--> 2550 mV at 1500 mV 
axp22_rtc: 3000 mV 
axp22_aldo1: 700 <--> 3300 mV at 3000 mV 
axp22_aldo2: 700 <--> 3300 mV at 2500 mV 
axp22_aldo3: 700 <--> 3300 mV at 3000 mV 
axp22_dldo1: 700 <--> 3300 mV at 700 mV 
axp22_dldo2: 700 <--> 3300 mV at 1800 mV 
axp22_dldo3: 700 <--> 3300 mV at 700 mV 
axp22_dldo4: 700 <--> 3300 mV at 700 mV 
axp22_eldo1: 700 <--> 3300 mV at 1800 mV 
axp22_eldo1: supplied by axp22_dcdc1
axp22_eldo2: 700 <--> 3300 mV at 700 mV 
axp22_eldo2: supplied by axp22_dcdc1
axp22_eldo3: 700 <--> 3300 mV at 700 mV 
axp22_eldo3: supplied by axp22_dcdc1
axp22_dc5ldo: 700 <--> 1400 mV at 1100 mV 
axp22_ldoio0: 700 <--> 3300 mV at 3800 mV 
axp22_ldoio1: 700 <--> 3300 mV at 3800 mV 
axp22_dc1sw: at 700 mV 
axp22_dc1sw: supplied by axp22_dcdc1
input: axp22-supplyer as /devices/platform/axp22_board/axp22-supplyer.20/input/input0

### Boot log during Uboot

```
[      1.444][mmc]: ---------------mmc->clock 50000000-----------
[      1.449][mmc]: ---------------mmc->bus_width 4--------------
[      1.455][mmc]: SD/MMC Card: 4bit, capacity: 7456MB
[      1.460][mmc]: boot0 capacity: 4000KB,boot1 capacity: 4000KB
```

### DRAM log

```
[    0.566478] [ddrfreq] dram_clk value is 552
[    0.566489] [ddrfreq] sunxi_ddrfreq_max=552000
[    0.566499] [ddrfreq] dram_type value is 3
[    0.566509] [ddrfreq] dram_zq value is 0x3bbb
[    0.566519] [ddrfreq] dram_odt_en value is 1
[    0.566530] [ddrfreq] dram_para1 value is 0x10f20400
[    0.566541] [ddrfreq] dram_para2 value is 0x1000
[    0.566551] [ddrfreq] dram_mr0 value is 0x1c70
[    0.566561] [ddrfreq] dram_mr1 value is 0x40
[    0.566571] [ddrfreq] dram_mr2 value is 0x18
[    0.566581] [ddrfreq] dram_mr3 value is 0x0
[    0.566591] [ddrfreq] dram_tpr0 value is 0x47214f
[    0.566601] [ddrfreq] dram_tpr1 value is 0x1c2294b
[    0.566612] [ddrfreq] dram_tpr2 value is 0x61043
[    0.566622] [ddrfreq] dram_tpr3 value is 0x0
[    0.566632] [ddrfreq] dram_tpr4 value is 0x0
[    0.566642] [ddrfreq] dram_tpr5 value is 0x0
[    0.566652] [ddrfreq] dram_tpr6 value is 0x0
[    0.566662] [ddrfreq] dram_tpr7 value is 0x0
[    0.566672] [ddrfreq] dram_tpr8 value is 0x0
[    0.566682] [ddrfreq] dram_tpr9 value is 0x0
[    0.566692] [ddrfreq] dram_tpr10 value is 0x0
[    0.566702] [ddrfreq] dram_tpr11 value is 0x0
[    0.566712] [ddrfreq] dram_tpr12 value is 168
[    0.566721] [ddrfreq] sunxi_ddrfreq_min=168000
[    0.566732] [ddrfreq] dram_tpr13 value is 0x10901
```

## Loggin in

```
microcom -p /dev/ttyUSB0 -s 115200
press '2' to start FEL mode
```

In another terminal:
```
sudo ./sunxi-fel uboot u-boot-sunxi-with-spl.bin

```

This loads u-boot on the system.

### After some progress on another A33 system I understood a fex things about my u-boot failures

I need to specify the power lines and the RAM parameters according to the fex files, otherwise it does not boot directly on the machine. I added the parameters and reflashed with confidence the boot sector on the EMMC thinking that I would reinstall from fel mode if it did not work.

IT WAS A MISTAKE! Yes u-boot started, but could not find any EMMC and I COULD NOT ENTER the FEL mode
again! Below is the log of what I did from the armbian console:

```
patrick@lime-a33:~$ sudo dd if=u-boot-sunxi-with-spl.bin of=/dev/mmcblk2 bs=1024 seek=8 DO NOT DO THAT!!!
[sudo] Mot de passe de patrick : 
[  433.610039]  mmcblk2: p1 p2 p3 < p5 p6 p7 p8 p9 p10 p11 p12 >
[  433.615911] mmcblk2: p1 size 12378112 extends beyond EOD, truncated
592+1 enregistrements lus
592+1 enregistrements écrits
606832 octets (607 kB, 593 KiB) copiés, 0,0985589 s, 6,2 MB/s
patrick@lime-a33:~$ sync
```

The log shows:
```
�
U-Boot SPL 2026.01-rc2-g5b13f84438d6-dirty (Mar 16 2026 - 20:16:29 +0100)
DRAM: 1024 MiB
Trying to boot from MMC2
MMC Device 1 not found
spl: could not find mmc device 1. error: -19
Error: -19
SPL: Unsupported Boot Device!
SPL: failed to boot from all boot devices
### ERROR ### Please RESET the board ###
```

But I assumed would show:
```
HELLO! BOOT0 is starting!
boot0 version : 3.1.0
reg_addr 0x01f00100 =0x00000000
reg_addr 0x01f00104 =0x00000000
reg_addr 0x01f00108 =0x00000000
reg_addr 0x01f0010c =0x00000000
reg_addr 0x01f00110 =0x00000000
reg_addr 0x01f00114 =0x00000000
DRAM DRIVE INFO: V1.5
DRAM CLK =552 MHZ
DRAM simple test OK.
dram size =1024
card boot number = 2
card no is 2
sdcard 2 line count 0
[mmc]: mmc driver ver 2014-07-07 16:54
[mmc]: ***Try SD card 2***
[mmc]: mmc 2 cmd 8 timeout, err 0x00000100
[mmc]: mmc 2 cmd 8 err 0x00000100
[mmc]: mmc 2 send if cond failed
[mmc]: mmc 2 cmd 55 timeout, err 0x00000100
[mmc]: mmc 2 cmd 55 err 0x00000100
[mmc]: mmc 2 send app cmd failed
[mmc]: ***Try MMC card 2***
[mmc]: MMC ver 5.0
[mmc]: SD/MMC Card: 4bit, capacity: 7456MB
[mmc]: vendor: Man 0x00150100 Snr 0x005c1dfe
[mmc]: product: 8WPD3
[mmc]: revision: 5.2
[mmc]: ***SD/MMC 2 init OK!!!***
sdcard 2 init ok
The size of uboot is 0x000bc000.
sum=0xb3d23440
src_sum=0xb3d23440
set_mmc_para,sdly 50M 0
set_mmc_para,sdly 25M 0
Succeed in loading uboot from sdmmc flash.
Ready to disable icache.
Jump to secend Boot.
[      0.332]

U-Boot SPL 2026.01-rc2-g5b13f84438d6-dirty (Mar 16 2026 - 20:16:29 +0100)
DRAM: 1024 MiB
Trying to boot from MMC2
MMC Device 1 not found
spl: could not find mmc device 1. error: -19
Error: -19
SPL: Unsupported Boot Device!
SPL: failed to boot from all boot devices
### ERROR ### Please RESET the board ###
```

The primary bootloader does not show up. My u-boot starts but it does not find the EMMC and fails without FEL mode.
Until now, unless the one time I destroyed the Boot0 sector, I was able to boot in FEL mode.

### I understand:

This is the second time I destroyed my boot0 sectors.
Because they can be seen as separate partitions in liunx, I assumed that boot0 was outside of the EMMC. But in fact, the first sectors of the flash are boot0. Because it is a new soldered version of the EMMC, I must have forgotten to lock them back when programming it.
My attemps to boot from the SD card instead of soldering a new chip failed because I had no proper memory/power rails setup in my u-boot. Only chainloading worked. The memory was then intialised because of the previous initialisation from the stock u-boot. My memory setup was wrong, and I could not write my bootloader because the boot sectors where protected.
Now, I will be able to have a proper u-boot chainloaded from the first one, but before changing the EMMC, I will retry my SD card mod and use fel-sdboot.sunxi on an SD card to enable FEL mode.
And until I can get FEL mode from my u-boot, I will chainload.

So at 8K we have the primary bootloader in a protected area. And after 0xA000 we have the secondary bootloader which is a u-boot.bin type.
On my two systems this secondary boot was located at 0x12A6000.

Turns out my new EMMC seemed not fully soldered such as it does not enable the 8bit interface. The Boot0 sectors shows up but not the other data.
-> in fact the soldering whent wel it seems, and the problem is already seen on the original firmware which boots fine:
* The fex file shows that emmc2 is disabled, I assume that the sunxi u-boot source code has been patched for a custom emmc init.
* In the stock boot, we see a clock reduced to 50Mhz and only 4 bits used instead of 8.
Once this is applied in the device tree, and once u-boot is compiled with mmc mode command, we can list the emmc partitions in u-boot and boot over emmc and not USB.
We can also use the device as a mass storage system.

https://docs.u-boot.org/en/latest/usage/cmd/mmc.html

In u-boot, mount the mmc2 in sd card speed mode (50Mhz):
```
=> mmc dev 1 0 1
=> mmc part
=> mmc rescan
=> ums 0 mmc 1
```

The parts apear in linux, we can dump the EMMC or configure the boot process:

Using the m200 as a mass storage (not from Armbian):
```
sudo dd if=sunxi_env.img of=/dev/sde5
```

However it is riskied to do things like this the from Armbian console. You will have soon destroyed one of your drives instead of programmed the m200.

## Installing on the flash.

We cannot at all replace Boot0, too risky. We can flash the stage two in place of the sunxi one an see what is going on.
Flash my u-boot proper to 0x12A6000 to see if it works.

From Armbian:
```
sudo dd if=u-boot-dtb.bin of=/dev/mmcblk2 bs=512 seek=38192
```

This does not work, stage 1 reports this:

```
[mmc]: ***SD/MMC 2 init OK!!!***
sdcard 2 init ok
ERROR! NOT find the head of uboot.
Ready to disable icache.
Jump to Fel.
```

But the chainloaded uboot would now have access to the EMMC.

No chainload works with EMMC, loading linux from th esunxi bootloader fials, event with their zImage.
The system is so closed, that I do not want to change Boot0. And I replaced my EMMC twice so enoug.
However the MMC performances are great compared to a Sandisk Cruzer blade. I made my tests for a while on a USB3 memory stick. It is gread but Armbian gives a warning "slow drive" with the Sandisk.
I have found a way to encasulate u-boot-dtb.bin in the sunxi format.
I will make a app to encapsulate mainline u-boot in sunxi format.
It wil be called sunxisecondstagetool.

#$ sunxisecondstagetool u-boot-dtb.bin

## And rebrick!

I managed to overwrite again the EMMC! Using the wrong command, and the write protection failed prior to that. While I double checked it did not work.

### Boor protection:

```
cat /sys/block/mmcblk2boot1/ro
cat /sys/block/mmcblk2boot1/force_ro
and
sudo mmc extcsd read /dev/mmcblk2 | grep -E 'BOOT_WP|BOOT_CONFIG_PROT|PARTITION_CONFIG|USER_WP'
```

* BOOT_WP: 0x00 → no boot partition write protection set
* nonzero BOOT_WP → temporary or permanent boot write protection is enabled

### A33 core schematics.

I found some schematis for the A33 Core board (https://github.com/xianxuhappy/A33_M2).
So, the only positive thing, is that if you brick the board, there is a sdio1 on the wifi chip. So maybe after removing the emmc, the chip will boot on SDC1.

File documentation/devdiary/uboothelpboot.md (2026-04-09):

```
U-Boot SPL 2025.04-rc5 (Oct 19 2025 - 19:35:59 +0200)
DRAM: 1024 MiB
Trying to boot from FEL

U-Boot 2025.04-rc5 (Oct 19 2025 - 19:35:59 +0200) Allwinner Technology

CPU:   Allwinner A33 (SUN8I 1667)
Model: Zortrax A33-M200
DRAM:  1 GiB
Core:  61 devices, 21 uclasses, devicetree: separate
WDT:   Not starting watchdog@1c20ca0
MMC:   mmc@1c11000: 1
Loading Environment from FAT... ** Bad device specification mmc 0 **
Unknown monitor
Unknown monitor
In:    serial,usbkbd
Out:   serial,vidconsole
Err:   serial,vidconsole
Net:   No ethernet found.

starting USB...
Bus usb@1c1a000: USB EHCI 1.00
Bus usb@1c1a400: USB OHCI 1.0
scanning bus usb@1c1a000 for devices... 1 USB Device(s) found
scanning bus usb@1c1a400 for devices... 1 USB Device(s) found
       scanning usb for storage devices... 0 Storage Device(s) found
Hit any key to stop autoboot:  0 
=> help
?         - alias for 'help'
base      - print or set address offset
bdinfo    - print Board Info structure
bind      - Bind a device to a driver
blkcache  - block cache diagnostics and control
boot      - boot default, i.e., run 'bootcmd'
bootd     - boot default, i.e., run 'bootcmd'
bootefi   - Boots an EFI payload from memory
bootelf   - Boot from an ELF image in memory
bootflow  - Boot flows
bootm     - boot application image from memory
bootp     - boot image via network using BOOTP/TFTP protocol
bootvx    - Boot vxWorks from an ELF image
bootz     - boot Linux zImage image from memory
cls       - clear screen
cmp       - memory compare
coninfo   - print console devices and information
cp        - memory copy
crc32     - checksum calculation
cyclic    - Cyclic
dhcp      - boot image via network using DHCP/TFTP protocol
dm        - Driver model low level access
echo      - echo args to console
editenv   - edit environment variable
eficonfig - provide menu-driven UEFI variable maintenance interface
env       - environment handling commands
exit      - exit script
ext2load  - load binary file from a Ext2 filesystem
ext2ls    - list files in a directory (default /)
ext4load  - load binary file from a Ext4 filesystem
ext4ls    - list files in a directory (default /)
ext4size  - determine a file's size
false     - do nothing, unsuccessfully
fatinfo   - print information about filesystem
fatload   - load binary file from a dos filesystem
fatls     - list files in a directory (default /)
fatmkdir  - create a directory
fatrm     - delete a file
fatsize   - determine a file's size
fatwrite  - write file into a dos filesystem
fdt       - flattened device tree utility commands
fstype    - Look up a filesystem type
fstypes   - List supported filesystem types
go        - start application at address 'addr'
gpio      - query and control gpio pins
gpt       - GUID Partition Table
help      - print command description/usage
iminfo    - print header information for application image
imxtract  - extract a part of a multi-image
itest     - return true/false on integer compare
lcdputs   - print string on video framebuffer
ln        - Create a symbolic link
load      - load binary file from a filesystem
loadb     - load binary file over serial line (kermit mode)
loads     - load S-Record file over serial line
loadx     - load binary file over serial line (xmodem mode)
loady     - load binary file over serial line (ymodem mode)
loop      - infinite loop on address range
ls        - list files in a directory (default /)
md        - memory display
mii       - MII utility commands
mm        - memory modify (auto-incrementing address)
mmc       - MMC sub system
mmcinfo   - display MMC info
mw        - memory write (fill)
net       - NET sub-system
nm        - memory modify (constant address)
panic     - Panic with optional message
part      - disk partition related commands
ping      - send ICMP ECHO_REQUEST to network host
pinmux    - show pin-controller muxing
poweroff  - Perform POWEROFF of the device
printenv  - print environment variables
pxe       - get and boot from pxe files
random    - fill memory with random pattern
reset     - Perform RESET of the CPU
run       - run commands in an environment variable
save      - save file to a filesystem
saveenv   - save environment variables to persistent storage
setcurs   - set cursor position within screen
setenv    - set environment variables
setexpr   - set environment variable as the result of eval expression
showvar   - print local hushshell variables
size      - determine a file's size
sleep     - delay execution for some time
source    - run script from memory
sysboot   - command to get and boot from syslinux files
test      - minimal test like /bin/sh
tftpboot  - load file via network using TFTP protocol
true      - do nothing, successfully
unbind    - Unbind a device from a driver
usb       - USB sub-system
usbboot   - boot from USB device
version   - print monitor, compiler and linker version
=> 

=> part list usb 0

Partition Map for usb device 0  --   Partition Type: DOS

Part	Start Sector	Num Sectors	UUID		Type
  1	32        	30031840  	00000000-01	0c

mmc read <ram_addr> <start_sector> <num_sectors>
mmc read 0x42000000 1 0x2D000
fatwrite usb 0:1 0x42000000 boot0.img 
mmc read 0x42000000 0x2D001 0x2D000
fatwrite usb 0:1 0x42000000 boot1.img 
mmc read 0x42000000 0x5A001 0x2D000
...
mmc read 0x42000000 0x276001 0x2D000
fatwrite usb 0:1 0x42000000 boot14.img size in 32bits!!!
mmc read 0x42000000 0x2A3001 0x2D000
fatwrite usb 0:1 0x42000000 boot15.img 

total 1509949440   0x2D0000 secteurs
188743680 octets pour 0x2D0000 / 8

   # Read boot image to RAM (into $loadaddr)
=> part start mmc 1 boot boot_start
=> part size mmc 1 boot boot_size
=> mmc read $loadaddr $boot_start $boot_size

   # Read DTBO image to RAM (into $dtboaddr)
=> part start mmc 1 dtbo dtbo_start
=> part size mmc 1 dtbo dtbo_size
=> mmc read $dtboaddr $dtbo_start $dtbo_size

   # Copy required DTB blob (into $fdtaddr)
=> abootimg get dtb --index=0 dtb0_start dtb0_size
=> cp.b $dtb0_start $fdtaddr $dtb0_size

   # Merge required DTBO blobs into DTB blob
=> fdt addr $fdtaddr 0x100000
=> adtimg addr $dtboaddr
=> adtimg get dt --index=0 $dtbo0_addr
=> fdt apply $dtbo0_addr

   # Boot Android
=> bootm $loadaddr $loadaddr $fdtaddr
```

## Read the boot partition

Part	Start Sector	Num Sectors	UUID		Type              Secteur  Taille
  1	2990080   	12378112  	00000000-01	0b Boot           0x2DA000          6.3GB - Android
  2	73728     	65536     	00000000-02	06      bootloader
  3	1         	2850816   	00000000-03	05 Extd
  5	139264    	32768     	00000000-05	83   x  env       0x22000    0x8000
  6	172032    	32768     	00000000-06	83   x  boot      0x2A000    0x8000 Android
  7	204800    	1572864   	00000000-07	83      system    0x32000  0x180000 800MB zortrax uboot boots on it
  8	1777664   	32768     	00000000-08	83      misc      0x1B2000   0x8000 Vide
  9	1810432   	65536     	00000000-09	83   x  recovery  0x1BA000  0x10000 Android
 10	1875968   	1048576   	00000000-0a	83      cache     0x1CA000 0x100000 500MB
 11	2924544   	32768     	00000000-0b	83      metadata  0x2CA000   0x8000 Vide
 12	2957312   	32768     	00000000-0c	83      private   0x2D2000   0x8000 Vide

DOS/MBR boot sector (from the first sectors of the EMMC);
partition 1 : ID=0xb, active, start-CHS (0x0,0,0), end-CHS (0x0,0,0), startsector 2990080, 12378112 sectors;
partition 2 : ID=0x6, start-CHS (0x0,0,0), end-CHS (0x0,0,0), startsector 73728, 65536 sectors;
partition 3 : ID=0x5, start-CHS (0x0,0,0), end-CHS (0x0,0,0), startsector 1, 2850816 sectors

```
$ sudo fdisk -l emmcstart.img
Device          Boot   Start      End  Sectors  Size Id Type
emmcstart.img1  *    2990080 15368191 12378112  5,9G  b W95 FAT32   BOOT
emmcstart.img2         73728   139263    65536   32M  6 FAT16       Bmp images and shit
emmcstart.img3             1  2850816  2850816  1,4G  5 Extended
emmcstart.img5        139264   172031    32768   16M 83 Linux       env          uboot env, text
emmcstart.img6        172032   204799    32768   16M 83 Linux       boot         ANDROID
emmcstart.img7        204800  1777663  1572864  768M 83 Linux       system     - android linux
emmcstart.img8       1777664  1810431    32768   16M 83 Linux       misc       - empty
emmcstart.img9       1810432  1875967    65536   32M 83 Linux       recovery     ANDROID
emmcstart.img10      1875968  2924543  1048576  512M 83 Linux       cache
emmcstart.img11      2924544  2957311    32768   16M 83 Linux       metadata   - empty
emmcstart.img12      2957312  2990079    32768   16M 83 Linux       private    - empty
```

The first disk sector is the MBR sector.
Then at sector 16 whe have 64 sectors for sunxi spl (eGON.BT3) signature.
At sector 38192 whe have 1664 sectors for uboot proper.
Then at sector 73728 start the partition 2.

```
mmc read 0x42000000 0x22000 0x8000
fatwrite usb 0:1 0x42000000 env.img 0x1000000

mmc read 0x42000000 0x2A000 0x8000
fatwrite usb 0:1 0x42000000 boot.img 0x1000000

mmc read 0x42000000 0x1BA000 0x10000
fatwrite usb 0:1 0x42000000 recovery.img 0x2000000
```
# Changing the env bootdelay=0 to 2

```
fatload usb 0:1 0x42000000 env.img 0x1000000
mmc write 0x42000000 0x22000 0x8000

mmc read 0x42000000 0x1CA000 0x8000
md 42000000
```

# Saving the bootloader partition
```
mmc dev 1
usb start
mmc read 0x42000000 0x12000 0x10000
fatwrite usb 0:1 0x42000000 bootloader.img 0x2000000
usb stop
```
# Misc
```
mmc read 0x42000000 0x1B2000 0x8000
fatwrite usb 0:1 0x42000000 misc.img 0x1000000
```
# Metadata
```
mmc read 0x42000000 0x2CA000 0x8000
fatwrite usb 0:1 0x42000000 metadata.img 0x1000000
```
# Private
```
mmc read 0x42000000 0x2D2000 0x8000
fatwrite usb 0:1 0x42000000 private.img 0x1000000
```
# system
```
mmc read 0x42000000 0x32000 0x8000
fatwrite usb 0:1 0x42000000 system.img 0x1000000
```
# Read magic.bin from bootloader partition
```
fatload mmc 1:1 0x42000000 magic.bin 0x200
fatwrite usb 0:1 0x42000000 magic.bin 0x200
usb stop
```
# Read the start of the mmc
```
mmc read 0x42000000 0x0000 0x12000
fatwrite usb 0:1 0x42000000 emmcstart.img 0x2400000
```
eGon
uboot

file emmcstart.img 
emmcstart.img: DOS/MBR boot sector; partition 1 : ID=0xb, active, start-CHS (0x0,0,0), end-CHS (0x0,0,0), startsector 2990080, 12378112 sectors; partition 2 : ID=0x6, start-CHS (0x0,0,0), end-CHS (0x0,0,0), startsector 73728, 65536 sectors; partition 3 : ID=0x5, start-CHS (0x0,0,0), end-CHS (0x0,0,0), startsector 1, 2850816 sectors

FILES=$(find .)
for f in $FILES; do xxd "${f}" | grep "d00d" | grep "feed"; done

## If the uboot image contains a lagecy FIT image, i will tru to extract the files

```
dd if=emmcstart.img of=extracted.bin bs=1 skip=$((0x12AB3C4)) count=$((1024*1024))

dumpimage -l  should do something -> no, and the uboot is a raw arm executable.
```

finding the legacy FIT image magic: 0x56190527

# Second FEX binary
Cut part002.bin from 0x78E38 to 0x82AC0 and call this zortraxm200.dtb.
```
dd if=part_0002.bin of=zortraxm200_2_script.bin bs=1 skip=$((0x78E38)) count=$((0x82AC0 - 0x78E38))
```

# First Fex binary
```
dd if=part_0002.bin of=zortraxm200_1_script.bin bs=1 skip=$((0x64E38)) count=$((0x6ed78 - 0x64e38))
```
### So it is no device tree but a compiled FEX file that is given to the kernel.

```
$:~/gitprint/sunxi-tools$ ./sunxi-fexc -v -I bin -O fex ../zortrax/legacyfit/zortraxm200_script.bin zortraxm200
.fex
./sunxi-fexc: from bin:../zortrax/legacyfit/zortraxm200_script.bin to fex:zortraxm200.fex
fexc-bin: ../zortrax/legacyfit/zortraxm200_script.bin: version: 1.2
fexc-bin: ../zortrax/legacyfit/zortraxm200_script.bin: size: 40072 (79 sections), header value: 40072
```

### For VBUS control on USB0 OTG
From uboot, this enables VBUS on the OTG usb port but I never used it in u-boot.
```
gpio clear 225
```
It is from a design mistake somewhere, we can see it in the vendor linux kernel log complaining about vbus detection.

### Boot using the usb stick (very usefull)

The rootfs is on /dev/sda2, /dev/sda1 is used for files.

```
setenv bootargs root=/dev/sda2 rootwait console=ttyS0,115200 rw
usb start
ext4load usb 0:2 0x42000000  boot/zImage
ext4load usb 0:1 0x43000000  sun8i-a33-zortrax-m200plus.dtb
bootz 0x42000000 - 0x43000000
```
```
setenv bootargs "root=/dev/sda2 rootwait console=ttyS0,115200"
saveenv
```
```
setenv bootcmd "usb start; ext4load usb 0:1 0x42000000 boot/zImage; ext4load usb 0:3 0x43000000 sun8i-a33-zortrax-m200plus.dtb; bootz 0x42000000 - 0x43000000"
saveenv
```
```
setenv "bootargs root=/dev/sda1 rootwait console=ttyS0,115200"
fatload usb 0:2 0x42000000 zimage
fatload usb 0:2 0x43000000 sun8i-a33-zortrax-m200plus.dtb
bootz 0x42000000 - 0x43000000
```
```
cd /mnt/
mkdir -p /mnt/ext4disk
mkdir -p /mnt/fat16disk
mount /dev/sda1 ext4disk/
mount /dev/mmcblk2p2 fat16disk
cp ext4disk/u-boot-*.bin fat16disk/
sync
reboot
```
```
mmc dev 2
fatload mmc 2:2 0x4A000000 u-boot-dtb.bin
go 0x4A000000
```
```
gpio clear 80
```

## The sytem drive on original zortrax emmc is partition 7

```
mount /dev/mmcblk2p7 system
```

## Partition the disk
```
sudo fdisk /dev/mmcblk0
or
sudo parted /dev/mmcblk0
```
The partition table, then uboot, then Armbian.

Or  $armbian-install

```
mount /dev/mmcblk2p1 ext4disk/
```

```
mmc dev 2
setenv devnum 2
saveenv
usb start
ext4load usb 0:3 0x43000000  sun8i-a33-zortrax-m200plus.dtb
run mmc_boot 
```

mais pas de console.

```
mmc dev 2
setenv devnum 2
setenv mmc_bootdev 2
run mmc_boot
```
```
setenv bootargs root=/dev/mmcblk1p1 rootwait console=ttyS0,115200
mmc dev 2
ext4load mmc 2:1 0x42000000  boot/zImage
ext4load mmc 2:1 0x43000000  boot/dtb/sun8i-a33-zortrax-m200plus.dtb
bootz 0x42000000 - 0x43000000
```

# Read the bootloader from the emmc at sector 16

```
mmc read 0x42000000 0x10 0x10
md 0x42000000
```

### Trying to use the original image

Restore the image
```
cd /mnt/
mount /dev/sda3 ext4disk/
cd ext4disk/
dd if=emmc.image of=/dev/mmcblk2 bs=4M conv=fsync
```
Save the env image
```
dd if=/dev/mmcblk2p5 of=sunxi_env.img bs=1k count=4
```
Change the env image
```
dd if=sunxi_env.img of=/dev/mmcblk2p5
```

Mout the FAT16 partition and copy the kernel and dtb
```
mkdir -p fat16disk
mount /dev/mmcblk2p2 fat16disk
cp boot/zImage fat16disk/
cp boot/dtb/sun8i-a33-zortrax-m200plus.dtb
umount fat16disk
```
```
cd /mnt/
mkdir -p ext4disk
mount /dev/sda1 ext4disk/
mount /dev/mmcblk2p2 fat16disk
cp ext4disk/u-boot-*.bin fat16disk/
```

cd
Delete the system partition and recreate it as ext4 (Do not do that! Keep it Zortrax and use a USB drive instead, theese lines are development notes).
```
parted /dev/mmcblk2
rm 3
mkpart primary ext4 2990080s 12378112s
quit
mkfs.ext4 /dev/mmcblk2p1
mount /dev/mmcblk2p1 ext4disk/
cd ext4disk/
tar xvf /moredata/armbian/Armbian-unofficial_25.11.0-trunk_Lime-a33_bookworm_legacy_6.6.75_minimal.img.tar.xz
umount ext4disk
```
```
using fdisk
d
1
n
p
1
2990080
15269887
w
```
```
mkfs.ext4 /dev/mmcblk2p1
blkid /dev/mmcblk2p1
```
```
mount -o loop,offset=4194304 Armbian-unofficial_25.11.0-trunk_Lime-a33_bookworm_legacy_6.6.75_minimal.img armbian_rootfs
mount /dev/mmcblk2p1 emmcarmbian/
rsync -aAXv armbian_rootfs/ emmcarmbian/

reboot
```

## Modify the uboot env to boot from mmcblk2p2
## Change bootcmd to load from mmc 2:2

```
setenv bootcmd 'mmc dev 2; fatload mmc 2:2 0x42000000 zImage; fatload mmc 2:2 0x43000000 sun8i-a33-zortrax-m200plus.dtb; bootz 0x42000000 - 0x43000000'
saveenv
```

## Change bootargs to root=/dev/mmcblk2p1

```
setenv bootargs 'root=/dev/mmcblk2p1 rootwait console=ttyS0,115200'
saveenv
reboot
```

```
fatls mmc 2:2
mmc dev 2
setenv bootargs root=/dev/mmcblk2p1 rootwait console=ttyS0,115200
fatload mmc 2:2 0x42000000 zimage
fatload mmc 2:2 0x43000000 sun8i-a33-zortrax-m200plus.dtb
bootz 0x42000000 - 0x43000000
```
OK boots from emmc if from uboot in FEL mode, a bit weird. Read only file system.

gives Wrong Image Format for bootm command
ERROR: can't get kernel image!

### Convet zImage to uImage

```
mkimage -A arm -O linux -T kernel -C none -a 0x40008000 -e 0x40008000 -n "Linux Kernel" -d zImage uImage
```

setenv bootargs root=/dev/sda2 rootwait console=ttyS0,115200
fatload mmc 2:2 0x42000000 uImage
fatload mmc 2:2 0x43000000 sun8i-a33-zortrax-m200plus.dtb
bootm 0x42000000 - 0x43000000

Fail

```
gzip -1 -c Image > Image.gz
mkimage -A arm -O linux -T kernel -C gzip -a 0x42008000 -e 0x42008000 -n "Linux Kernel" -d Image.gz uImage
```

Uncompressed:
Booting kernel from Legacy Image at 42000000 ...
   Image Name:   Linux Kernel
   Image Type:   ARM Linux Kernel Image (gzip compressed)
   Data Size:    11292864 Bytes = 10.8 MiB
   Load Address: 42000000
   Entry Point:  42000000
   Verifying Checksum ... OK
   Uncompressing Kernel Image ... 
Stuck

Using the Zortrax kernel:
```
mkimage -A arm -O linux -T kernel -C none -a 0x40008000 -e 0x40008000 -n "Linux Kernel" -d zImageZ uImage
```
undefined instruction
pc : [<4000800c>]	   lr : [<7fb153ac>]

### Boot

```
setenv bootargs root=/dev/mmcblk0p7 rootwait console=ttyS0,115200  init=/init
fatload mmc 2:2 0x42000000 uimage
fatload mmc 2:2 0x43000000 sun8i-a33-zortrax-m200plus.dtb
bootm 0x42000000 - 0x43000000
```
Boots and hangs?????

# Chainload uboot from the older one

```
mmc dev 2
fatload mmc 2:2 0x42000000 u-boot-sunxi-with-spl.bin 596216
go 0x42000000
```
fail
```
mmc dev 2
fatload mmc 2:2 0x40000000 u-boot-sunxi-with-spl.bin 596216
go 0x40000000
```
fail
```
mmc dev 2
fatload mmc 2:2 0x4A000000 u-boot-sunxi-with-spl.bin
go 0x4A000000
```
semi fail from the sunxi uboot
..P
U-Boot SPL 2026.01-rc2-gd9b92b4449b3-dirty (Nov 13 2025 - 19:01:00 +0100)
DRAM:

Maybe by specifying the DRAM settings

from last uboot
```
fatload mmc 2:2 0x43000000 u-boot-sunxi-with-spl.bin 596216
go 0x43000000
```
fail

```
mmc dev 2
fatload mmc 2:2 0x4A000000 u-boot.bin 563384
go 0x4A000000
```
Ok Chainload!!!!!! :o
But MMC is messed up

use u-boot-dtb.bin
```
mmc dev 2
fatload mmc 2:2 0x4A000000 u-boot-dtb.bin
go 0x4A000000
```
Ok Chainload.
But MMC is still messed up

using u-boot-dtb.bin with EMMC=2
```
mmc dev 2
fatload mmc 2:2 0x4A000000 u-boot-dtb.bin
go 0x4A000000
```
NOPE

using u-boot-dtb.bin with EMMC=2 from usb
```
usb start
ext4load usb 0:3 0x4A000000  u-boot-dtb.bin
go 0x4A000000
```
MMC ok but at 1 instead of 2

using u-boot-dtb.bin with only CONFIG_SPL_MMC from usb
```
usb start
ext4load usb 0:3 0x4A000000  u-boot-dtb.bin
go 0x4A000000
```
OK, with MMC 2 included

### The command to chainload u-boot from the stock bootloader

```
setenv vendorbootcmd "run setargs_mmc boot_normal"
setenv bootcmd "mmc dev 2; fatload mmc 2:2 0x4A000000 u-boot-dtb.bin; go 0x4A000000"
saveenv
```

```
fatls mmc 2:2
setenv bootargs root=/dev/mmcblk2p1 rootwait console=ttyS0,115200 
saveenv
fatload mmc 2:2 0x42000000 zimage
fatload mmc 2:2 0x43000000 sun8i-a33-zortrax-m200plus.dtb
bootz 0x42000000 - 0x43000000
```
FAILED] Failed to start systemd-re…ount Root and Kernel File Systems.
fstab problem, duck duck go > OpenAI GPT4.1
To get the UUID of the root partition:
blkid /dev/mmcblk2p1
UUID="33b43a40-9415-4958-b0be-6c5a1e17e26d"

Now from emmc with fixed fstab
```
mmc dev 2
fatload mmc 2:2 0x4A000000 u-boot-dtb.bin
go 0x4A000000
setenv bootargs root=/dev/mmcblk2p1 rootwait console=ttyS0,115200
```
Fucked up emmc

From usb fel mode with fixed fstab
Much better.

Only needs emmc detection from a chainloaded uboot. It works from fel mode but not when chainloading.
From EMMC with CONFIG_DM_RESET
nope

Adding mmc things in dts0
ofnode_read_u32_index: vmmc-supply: 0x11 (17)
ofnode_read_u32_index: vqmmc-supply: 0x11 (17)
Card did not respond to voltage select! : -110
mmc_init: -95, time 22
NOPE

## Booting by chain loading from the EMMC FAT16 part, and then loading not from the emmc but from the fat16 partition on usb
```
mmc dev 2
fatload mmc 2:2 0x4A000000 u-boot-dtb.bin
go 0x4A000000
setenv bootargs root=/dev/mmcblk2p1 rootwait console=ttyS0,115200
fatload usb 0:2 0x42000000 zimage
fatload usb 0:2 0x43000000 sun8i-a33-zortrax-m200plus.dtb
bootz 0x42000000 - 0x43000000
```

kernel panic, worked at some point -> because Android boot overwrote the partition
But boot fine now.

## Fatload from the emmc using sunxiboot, and call bootz from the chainloaded mainline uboot
```
mmc dev 2
fatload mmc 2:2 0x42000000 zimage
fatload mmc 2:2 0x43000000 sun8i-a33-zortrax-m200plus.dtb
fatload mmc 2:2 0x4A000000 u-boot-dtb.bin
go 0x4A000000
setenv bootargs root=/dev/mmcblk2p1 rootwait console=ttyS0,115200
bootz 0x42000000 - 0x43000000
```
Nope

using u-boot.img:
```
mmc dev 2
fatload mmc 2:2 0x4A000000 u-boot.img
bootm 0x4A000000
```
Wrong format, goes back to prompt

## Booting kernel from Legacy Image at 4a000000 ...

   Image Name:   U-Boot 2026.01-rc2-gd9b92b4449b3
   Image Type:   ARM U-Boot Firmware (uncompressed)
   Data Size:    563384 Bytes = 550.2 KiB
   Load Address: 4a000000
   Entry Point:  4a000000
   Verifying Checksum ... OK
Wrong Image Type for bootm command
ERROR: can't get kernel image!

use u-boot-dtb.img
```
mmc dev 2
fatload mmc 2:2 0x4A000000 u-boot-dtb.img
bootm 0x4A000000
```

## Booting kernel from Legacy Image at 4a000000 ...

   Image Name:   U-Boot 2026.01-rc2-gd9b92b4449b3
   Image Type:   ARM U-Boot Firmware (uncompressed)
   Data Size:    563384 Bytes = 550.2 KiB
   Load Address: 4a000000
   Entry Point:  4a000000
   Verifying Checksum ... OK
Wrong Image Type for bootm command
ERROR: can't get kernel image!

sunxi#fatload mmc 2:2 0x4A000000 uimage 
sunxi#bootm 0x4A000000

## Booting kernel from Legacy Image at 4a000000 ...

   Image Name:   Linux Kernel
   Image Type:   ARM Linux Kernel Image (uncompressed)
   Data Size:    10748704 Bytes = 10.3 MiB
   Load Address: 40008000
   Entry Point:  40008000
   Verifying Checksum ... OK
   Loading Kernel Image ... OK
OK
para err in disp_ioctl, cmd = 0xa,screen id = 1
[    118.337][mmc]: mmc exit start
[    118.341][mmc]: mmc 2 2xmode config clk
[    118.351][mmc]: mmc 2 2xmode config clk
[    118.363][mmc]: mmc 2 cmd 8 timeout, err 100
[    118.368][mmc]: smc 2 err, cmd 8,  RTO
[    118.373][mmc]: mmc 2 mmc cmd 8 err 0x00000100
[    118.377][mmc]: mmc send if cond failed
[    118.381][mmc]: mmc 2 cmd 55 timeout, err 100
[    118.385][mmc]: smc 2 err, cmd 55,  RTO
[    118.391][mmc]: mmc 2 mmc cmd 55 err 0x00000100
[    118.395][mmc]: send app cmd failed
[    118.428][mmc]: mmc 2 exit ok
[    118.431]
Starting kernel ...

```
setenv bootargs root=/dev/mmcblk1p1 rootwait console=ttyS0,115200 
fatload mmc 2:2 0x4A000000 uimage
fatload mmc 2:2 0x43000000 sun8i-a33-zortrax-m200plus.dtb
bootm 0x4A000000 - 0x43000000
```
NOPE

```
setenv bootargs root=/dev/mmcblk1p1 rootwait console=ttyS0,115200 
fatload mmc 2:2 0x4A000000 uimage
fatload mmc 2:2 0x43000000 sun8i-a33-zortrax-m200plus.dtb
bootm 0x4A000000 - 0x43000000
```
NOPE

go 0x42000000
Hangs and reboots

## DO NOT TRY AT HOME

!!!!!!!!!!!!!!! BRICKs the board !!!!!!!!!!!!!!!!!!!!
------------------- THIS BREAKS THE BOARD, NO FEL MODE AFTER THAT!!!! ------------------------
Removes the write protection (never do that):
echo 0 > /sys/block/mmcblk2boot0/force_ro
To flash new u-boot bootloader into boot partitions:
dd if=u-boot-sunxi-with-spl.bin of=/dev/mmcblk2boot0 bs=1024 seek=8 status=noxfer
Because it is loaded but hangs and does not help with anything but bricks the board
since the FEL mode is not available anymore.
!!!!!!!!!!!!!!! BRICKs the board !!!!!!!!!!!!!!!!!!!!

After that your board is a brick, you need to replace the EMMC with a new programmed one.
-----------------------------------------------------------------------------------------------

## Dump the bootlader stages
```
dd if=/dev/mmcblk2 bs=512 skip=16 count=1 | hexdump -C
dd if=/dev/mmcblk2 bs=512 skip=38192 count=1 | hexdump -C
```

## Uboot SPL

```
dd if=/dev/mmcblk2 bs=512 skip=16 count=1 | hexdump -C
```

U-Boot SPL area is 0x8000 (protected BOO0 partition). It is the program starting the FEL mode
and loading the secondary sunxi bootloader at sector 38192.

Trying to write uboot.img at the same place as the original zortrax uboot
dd if=u-boot.img of=/dev/mmcblk2 bs=512 seek=38192 conv=fsync
Does not work

The boot0 code is not able to load this code. It says:
```
[mmc]: ***SD/MMC 2 init OK!!!***
sdcard 2 init ok
ERROR! NOT find the head of uboot.
```
Turns out Sunxi has his format.

## Disguising our u-boot-dtb.bin as a sunxi code.

Allwinner gave the source code here https://github.com/allwinner-zh/bootloader.git and it shows all the checks it does.
Maybe we can alter out u-boot to passe the checks.

```
struct spare_boot_ctrl_head
{
	unsigned int  jump_instruction;   // one intruction jumping to real code
	unsigned char magic[8];           // ="u-boot"
	unsigned int  check_sum;          // generated by PC
	unsigned int  align_size;		  // align size in byte
	unsigned int  length;             // the size of all file
	unsigned int  uboot_length;       // the size of uboot
	unsigned char version[8];         // uboot version
	unsigned char platform[8];        // platform information
	int           reserved[1];        // stamp space, 16bytes align
};
```
Them bootloader is from 0x12A6000 to 0x1375FFF which is 851967 Bytes.
Our u-boot-dtb.bin is 574624 Bytes, it is possible so sneak it in.
I requires a tool building the decorum around it.

hexdump -C -n 1024 sunxi_zotrax_uboot_sect38192_1664sect.bin

### Field Recovery on copilot

jump_instruction (4 bytes)

Offset: 0x00000000
Value: 3e 01 00 ea
Interpretation: Little-endian, so the value is 0xEA00013E.

magic (8 bytes)
Offset: 0x00000004
Value: 75 62 6f 6f 74 00 00 00
Interpretation: ASCII string "uboot\0\0\0".

check_sum (4 bytes)
Offset: 0x0000000C
Value: b7 50 3a 24
Interpretation: Little-endian, so the value is 0x243A50B7.

align_size (4 bytes)
Offset: 0x00000010
Value: 00 40 00 00
Interpretation: Little-endian, so the value is 0x00004000 (16 KB).

length (4 bytes)
Offset: 0x00000014
Value: 00 c0 0b 00
Interpretation: Little-endian, so the value is 0x000BC000 (753,664 bytes).

uboot_length (4 bytes)
Offset: 0x00000018
Value: 00 00 0b 00
Interpretation: Little-endian, so the value is 0x000B0000 (720,896 bytes).

version (8 bytes)
Offset: 0x0000001C
Value: 31 2e 31 2e 30 00 00 00
Interpretation: ASCII string "1.1.0\0\0\0".

platform (8 bytes)
Offset: 0x00000024
Value: 31 2e 30 2e 30 00 00 00
Interpretation: ASCII string "1.0.0\0\0\0".

reserved (4 bytes)
Offset: 0x0000002C
Value: 00 00 00 4A
Interpretation: Little-endian, so the value is 0x4A000000.

## Our thing

```
struct spare_boot_ctrl_head
{
	unsigned int  jump_instruction;   // one intruction jumping to real code pout our start
	unsigned char magic[8];           // Constant              const "uboot" 
	unsigned int  check_sum;          // generated by PC to be programmed
	unsigned int  align_size;		  // align size in byte  0x00004000 16KB, uboot_length is a multiple of it, we wil pad with zeros
	unsigned int  length;             // the size of all file our file size
	unsigned int  uboot_length;       // the size of uboot (same as above we do not use fex data, our index is in the bin data)
	unsigned char version[8];         // uboot version         const "1.1.0\0\0\0"
	unsigned char platform[8];        // platform information  const "1.0.0\0\0\0"
	int           reserved[1];        //stamp space, 16bytes align const 0x4A00000
};
```
Followed by
```
struct spare_boot_data_head
{
	unsigned int				dram_para[32];
	int							run_clock;				// Mhz
	int							run_core_vol;			// mV
	int							uart_port;              // UART���������
	normal_gpio_cfg             uart_gpio[2];           // UART������(���Դ�ӡ��)GPIO��Ϣ
	int							twi_port;               // TWI���������
	normal_gpio_cfg             twi_gpio[2];            // TWI������GPIO��Ϣ�����ڿ���TWI
	int		                    work_mode;              // ����ģʽ
    int                         storage_type;           // �洢��������  0��nand   1��sdcard    2: spinor
    normal_gpio_cfg             nand_gpio[32];          // nand GPIO��Ϣ
    char						nand_spare_data[256];	// nand ������Ϣ
    normal_gpio_cfg             sdcard_gpio[32];		// sdcard GPIO��Ϣ
    char             			sdcard_spare_data[256];	// sdcard ������Ϣ
    int							reserved[2];			// ��������λ, 16bytes align
};

[Copilot]
Assuming this dump starts at spare_boot_data_head offset 0x00 (your line starts at absolute 0x30, i.e. right after spare_boot_ctrl_head), and values are little-endian:

dram_para[32] (0x00..0x7F): all 0x00000000
run_clock (0x80): 0x000003F0 = 1008 MHz
run_core_vol (0x84): 0x000004B0 = 1200 mV
uart_port (0x88): 0x00000000 = UART0
normal_gpio_cfg (8 bytes each, typical layout: port, pin, mul_sel, pull, drv, data, rsv0, rsv1):

uart_gpio[0] (0x8C): 06 02 03 01 FF FF 00 00
port=6, pin=2, mul=3, pull=1, drv/data=FF (default/ignored)
uart_gpio[1] (0x94): 06 04 03 01 FF FF 00 00
port=6, pin=4, mul=3, pull=1, drv/data=FF
twi_port (0x9C): 0x00000000 = TWI0
twi_gpio[0] (0xA0): 08 02 02 FF FF FF 00 00
port=8, pin=2, mul=2
twi_gpio[1] (0xA8): 08 03 02 FF FF FF 00 00
port=8, pin=3, mul=2
Then:

work_mode (0xB0): 0x00000000
storage_type (0xB4): 0x00000000 (NAND per your comment)
Everything shown after that is mostly zero and falls into nand_gpio[] / spare data region. The FF..FF block near absolute 0x3E8 is inside that area, not the final reserved[2] yet.
[/Copilot]
```

# Read the sunxi boot spl area

```
mmc dev 2
mmc read 0x42000000 0x10 0x10
md 0x42000000
```
0x1376000 - 0x12A6000 = D0000
```
dd if=/dev/zero of=/dev/mmcblk2 bs=512 count=1664 seek=38192 status=noxfer
dd if=u-boot-dtb.bin of=/dev/mmcblk2 bs=512 seek=38192 count=1101
dd if=/dev/mmcblk2 bs=512 skip=38192 count=1 | hexdump -C
dd if=legacy_3p4/sunxi_zotrax_uboot_sect38192_1664sect.bin of=/dev/mmcblk2 bs=512 seek=38192 count=1664
dd if=/dev/mmcblk2 bs=512 skip=38192 count=1 | hexdump -C
```

$:~/moredata/emmc/Zortrax_OK$ /usr/local/bin/sunxi-fw info -v emmc.image 
@   0: mbr: DOS MBR
	part 1: type: 0B, offset:  2990080 sectors, size: 12378112 sectors
	part 2: type: 06, offset:    73728 sectors, size:    65536 sectors
	part 3: type: 05, offset:        1 sectors, size:  2850816 sectors
	first partition starts at 0 KB
@   1: mbr: DOS MBR
	part 1: type: 83, offset:   139263 sectors, size:    32768 sectors
	part 2: type: 05, offset:        1 sectors, size:    32768 sectors
	first partition starts at 0 KB
@   2: mbr: DOS MBR
	part 1: type: 83, offset:   172030 sectors, size:    32768 sectors
	part 2: type: 05, offset:        2 sectors, size:    32768 sectors
	first partition starts at 1 KB
@   3: mbr: DOS MBR
	part 1: type: 83, offset:   204797 sectors, size:  1572864 sectors
	part 2: type: 05, offset:        3 sectors, size:  1572864 sectors
	first partition starts at 1 KB
@   4: mbr: DOS MBR
	part 1: type: 83, offset:  1777660 sectors, size:    32768 sectors
	part 2: type: 05, offset:        4 sectors, size:    32768 sectors
	first partition starts at 2 KB
@   5: mbr: DOS MBR
	part 1: type: 83, offset:  1810427 sectors, size:    65536 sectors
	part 2: type: 05, offset:        5 sectors, size:    65536 sectors
	first partition starts at 2 KB
@   6: mbr: DOS MBR
	part 1: type: 83, offset:  1875962 sectors, size:  1048576 sectors
	part 2: type: 05, offset:        6 sectors, size:  1048576 sectors
	first partition starts at 3 KB
@   7: mbr: DOS MBR
	part 1: type: 83, offset:  2924537 sectors, size:    32768 sectors
	part 2: type: 05, offset:        7 sectors, size:    32768 sectors
	first partition starts at 3 KB
@   8: mbr: DOS MBR
	part 1: type: 83, offset:  2957304 sectors, size:    32768 sectors
	first partition starts at 1478652 KB
@   9: mbr: DOS MBR
	part 1: type: 83, offset:  6135799 sectors, size:     1024 sectors
	part 2: type: 05, offset:        9 sectors, size:     1024 sectors
	first partition starts at 4 KB
@  10: mbr: DOS MBR
	part 1: type: 83, offset:  6136822 sectors, size:    31744 sectors
	part 2: type: 05, offset:       10 sectors, size:    31744 sectors
	first partition starts at 5 KB
@  11: mbr: DOS MBR
	part 1: type: 83, offset:  6168565 sectors, size:   163840 sectors
	part 2: type: 05, offset:       11 sectors, size:   163840 sectors
	first partition starts at 5 KB
@  12: mbr: DOS MBR
	part 1: type: 83, offset:  6332404 sectors, size:    32768 sectors
	first partition starts at 3166202 KB
@  16: boot0: Allwinner boot0
	size: 32768 bytes
	eGON checksum matches: 0x67a6f033
	DRAM parameters:           A64        H616        A133   
		DRAM clock  :         552         552         552
		DRAM type   :         0x3         0x3         0x3
		ZQ value    :      0x3bbb           -           -
		ODT enabled :         0x1      0x1000           -
		DX ODT      :           -      0x3bbb      0x3bbb
		DX DRI      :           -         0x1         0x1
		CA DRI      :           -  0x10f20400  0x10f20400
		PARA0       :           -           -      0x1000
		PARA1       :  0x10f20400      0x1c70      0x1c70
		PARA2       :      0x1000        0x40        0x40
		MR0         :      0x1c70        0x18        0x18
		MR1         :        0x40           0           0
		MR2         :        0x18    0x47214f    0x47214f
		MR3         :           0   0x1c2294b   0x1c2294b
		MR4         :           -     0x61043     0x61043
		TPR0        :    0x47214f        0xa8           0
		TPR1        :   0x1c2294b     0x10901           0
		TPR2        :     0x61043           0        0xa8
		TPR3        :           0           0     0x10901
		TPR12       :        0xa8           0           0
		TPR13       :     0x10901           0           0

### Sunxi boot roms release dates on the printer

mmcblk2boot0 primary bootloader:
[mmc]: mmc driver ver 2014-07-07 16:54

uboot:
U-Boot 2011.09-rc1 (Mar 21 2017 - 01:10:46) Allwinner Technology 

2011.09-rc1 compiled the 21 Mar 2017

### Fourth brick

I managed to load u-boot-dtb.bin from sunxi SPL, but the FEL mode in not enabled if it can boot the second stage.
And since the second stage boot failed with mainline u-boot, I was stuck.
I should have tested on a SD card on my ezeetab 96Q10 system.
Now I am good to replace my EMMC. I did not check if the MMC worked on the latest chainloadings.

#### Trying chainload on my last working printer

It seems that emmc works when chainloading now. So I will keep the chainloading process and never touch the zortrax bootloader again.

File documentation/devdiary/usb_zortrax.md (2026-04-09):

# Rev 2.2 and Rev 1.1

usb info

1: Hub,  USB Revision 2.0
 - u-boot EHCI Host Controller 
 - Class: Hub
 - PacketSize: 64  Configurations: 1
 - Vendor: 0x0000  Product 0x0000 Version 1.0
   Configuration: 1
   - Interfaces: 1 Self Powered 0mA
     Interface: 0
     - Alternate Setting 0, Endpoints: 1
     - Class Hub
     - Endpoint 1 In Interrupt MaxPacket 8 Interval 255ms

1: Hub,  USB Revision 1.10
 -  U-Boot Root Hub 
 - Class: Hub
 - PacketSize: 8  Configurations: 1
 - Vendor: 0x0000  Product 0x0000 Version 0.0
   Configuration: 1
   - Interfaces: 1 Self Powered 0mA
     Interface: 0
     - Alternate Setting 0, Endpoints: 1
     - Class Hub
     - Endpoint 1 In Interrupt MaxPacket 2 Interval 255ms

=> usb tree
USB device tree:
  1  Hub (480 Mb/s, 0mA)
     u-boot EHCI Host Controller 
   
  1  Hub (12 Mb/s, 0mA)
      U-Boot Root Hub 
   
### In Kernel log

[    0.565522] [usb_manager]: CONFIG_USB_SUNXI_USB0_OTG
[    0.565549] no usbc(0) det_vbus gpio and try to axp det_pin
[    0.565564] get usbc0(usb_restrict pin) failed

CONFIG_USB_SUNXI_USB0_OTG enables OTG and fixes the crash for Sunxi uboot branch in 2015

### Crash with USB0 enabled.
 
It was USB_GADGET and MUSB crashing the device in u-boot. Noo need for that.

### axp223

Le 5V entre à ACIN et sort à VBUS vers le connecteur USB0
La sortie vers VBUS (IPSOUT) est décidée soit par la pin N_VBUSEN à 0, soit par le bit 7 de 30H à 1 (default = 0x60, b0110 donc decidé par N_VBUSEN).

PH1 1=USB_slave 0=USB Host in usb_mode_script.sh -> connecté à usb ID pin 49 PH08 du SOM

USB_DRVVBUS, pin 25 du SOM va vers l'IC a 3 5 pattes ou est connecté IPSOUT (VBUS pin 48 du SOM).
USB_DRVVBUS est la pin 11 N_VBUSEN de l'axp223. C'est configuré en sortie sur le SOM.

Donc U4 est un transistor activé par N_VBUSEN.
* GND  IPDOUT selects VBUS
* High IPDOUT does not select VBUS

So DRIVEVBUS bit of 0x60 controls the output to the transistor+-.

#### FEX file

usb_id_gpio = port:PH08<0><1><default><default>
usb_det_vbus_gpio = "axp_ctrl"                     // to pin 49 PH08
usb_drv_vbus_gpio = port:power4<1><0><default><0>  // pin 25 to transistor?

### Enable USB0 VBUS using custom code

```
usb0vbus 1
```

### Clear PH1 in uboot

```
gpio clear 225
```

### 2 USB systems

* USB OTG                NOK   Custom driver, musb suports it.
https://linux-sunxi.org/USB_OTG_Controller_Register_Guide

* USB 1   -> EHCI OHCI    OK

### Cables

Uses JST PH2.0 9mm connectors

https://fr.aliexpress.com/item/1005004723638618.html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

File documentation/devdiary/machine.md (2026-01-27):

## Connect to the serial console

microcom -p /dev/ttyUSB0 -s 115200

## Linux boot

Kernel command line: console=ttyS0,115200

root=/dev/mmcblk0p7 
partitions=
    bootloader@mmcblk0p2
    env@mmcblk0p5
    boot@mmcblk0p6
    system@mmcblk0p7
    misc@mmcblk0p8
    recovery@mmcblk0p9
    cache@mmcblk0p10
    metadata@mmcblk0p11
    private@mmcblk0p12
    UDISK@mmcblk0p1 

[    0.000000] Memory: 1024MB = 1024MB total
[    0.000000] Memory: 845372k/845372k available, 203204k reserved, 90112K highmem

512 x 16bits = 1GB

## MMC

[mmc]: ***Try MMC card 2***
[mmc]: MMC ver 5.0
[mmc]: SD/MMC Card: 4bit, capacity: 7456MB
[mmc]: vendor: Man 0x00110100 Snr 0x00f15daa
[mmc]: product: 008G7
[mmc]: revision: 3.0
[mmc]: ***SD/MMC 2 init OK!!!***

## FEL mode

Enter FEL mode by pressing 2 on the serial console.
https://linux-sunxi.org/Retrieving_device_information
https://linux-sunxi.org/FEL/USBBoot

Press '2' on the console during boot to get to FEL mode on USB0. USB0 will be in device mode without VBUS (5V).

## Enter ADB mode

Press the home button when powering on, the board boots in ADB mode.
However no debug interface is given.

## LCD screen

Resolution 480 x 800

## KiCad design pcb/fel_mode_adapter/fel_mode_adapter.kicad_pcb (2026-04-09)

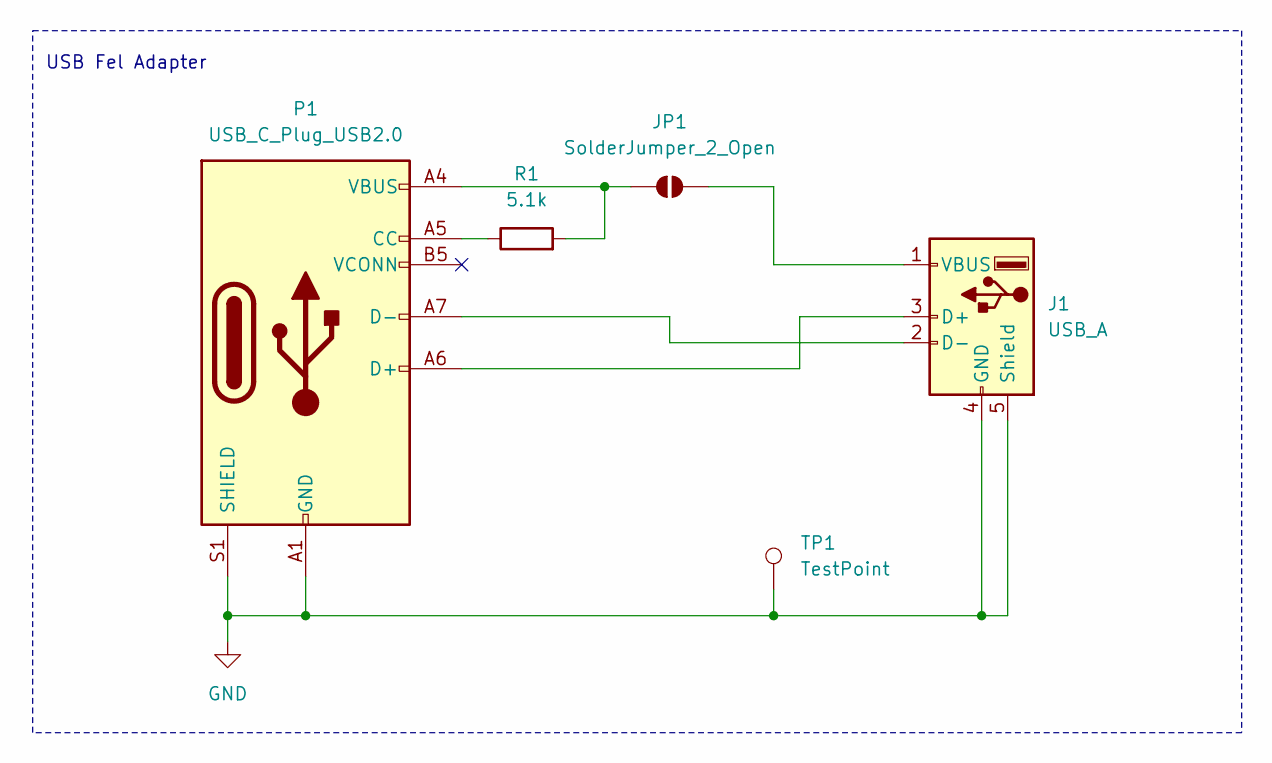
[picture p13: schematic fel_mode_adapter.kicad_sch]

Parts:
J1: USB_A; USB_A_Molex_48037-2200_Horizontal; farnell 2313729
JP1: SolderJumper_2_Open; SolderJumper-2_P1.3mm_Open_TrianglePad1.0x1.5mm
P1: USB_C_Plug_USB2.0; USB_C_Receptacle_G-Switch_GT-USB-7010ASV; farnell 3777659
R1: 5.1k; R_0805_2012Metric
TP1: TestPoint; TestPoint_Pad_D1.0mm

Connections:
GND: J1.4 (GND), J1.5 (Shield), P1.A1 (GND), P1.A12 (GND), P1.B1 (GND), P1.B12 (GND), P1.S1 (SHIELD), TP1.1
unnamed: J1.3 (D+), P1.A6 (D+)
unnamed: J1.2 (D-), P1.A7 (D-)
unnamed: J1.1 (VBUS), JP1.2 (B)
unnamed: JP1.1 (A), P1.A4 (VBUS), P1.A9 (VBUS), P1.B4 (VBUS), P1.B9 (VBUS), R1.2
unnamed: P1.A5 (CC), R1.1

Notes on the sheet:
USB Fel Adapter

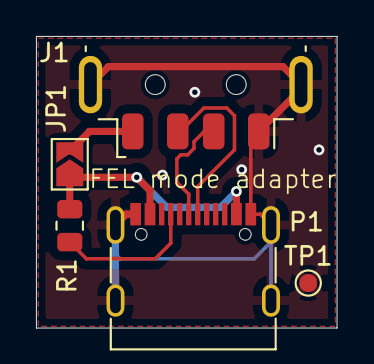
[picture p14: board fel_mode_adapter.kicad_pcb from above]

Board: 2 copper layers, 16.7 x 16.2 mm, 5 parts (0 on the bottom side), 6 nets.

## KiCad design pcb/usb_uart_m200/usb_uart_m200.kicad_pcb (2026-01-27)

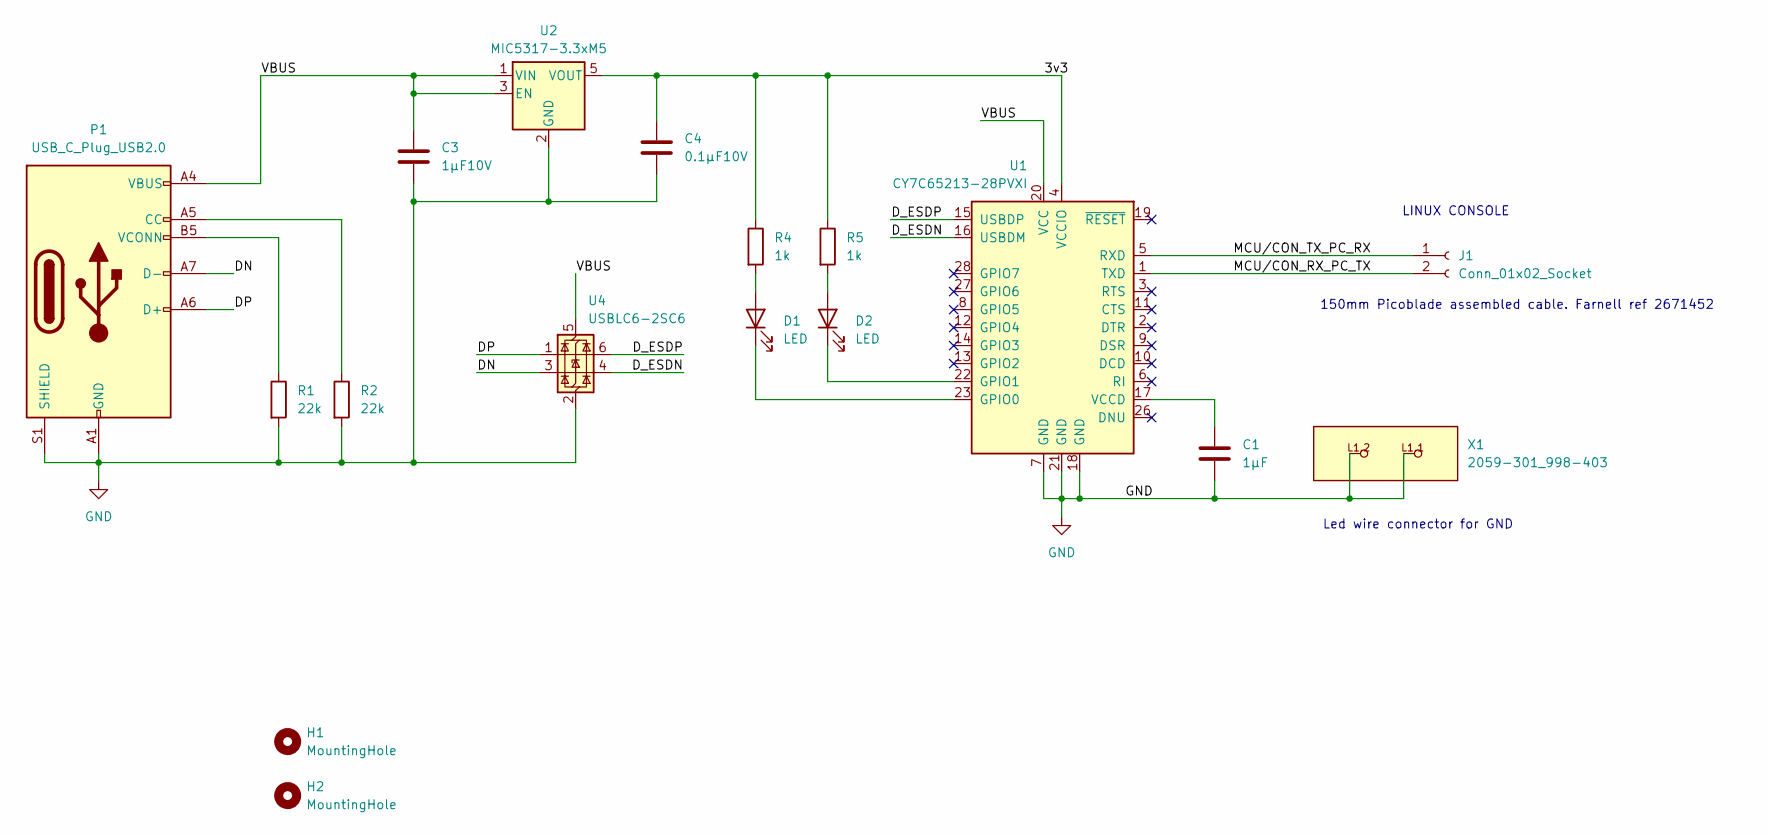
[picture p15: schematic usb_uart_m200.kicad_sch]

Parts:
C1: 1µF; C_0805_2012Metric
C3: 1µF10V; C_0805_2012Metric
C4: 0.1µF10V; C_0805_2012Metric
D1, D2: LED; LED_0805_2012Metric_Pad1.15x1.40mm_HandSolder
H1, H2: MountingHole; MountingHole_3.2mm_M3_DIN965_Pad_TopBottom
J1: Conn_01x02_Socket; Molex_PicoBlade_53047-0210_1x02_P1.25mm_Vertical; farnell 9733051
P1: USB_C_Plug_USB2.0; USB_C_Receptacle_G-Switch_GT-USB-7010ASV; farnell 3777659
R1, R2: 22k; R_0805_2012Metric; farnell 2073691
R4, R5: 1k; R_0805_2012Metric
U1: CY7C65213-28PVXI; SSOP-28_5.3x10.2mm_P0.65mm; farnell 2772892
U2: MIC5317-3.3xM5; SOT-23-5; farnell 2920683
U4: USBLC6-2SC6; SOT-23-6; farnell 1269406
X1: 2059-301_998-403; P-2059-301_998-403; farnell 2452830

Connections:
/3v3: C4.1, R4.1, R5.1, U1.4 (VCCIO), U2.5 (VOUT)
/DN: P1.A7 (D-), U4.3 (I/O2)
/DP: P1.A6 (D+), U4.1 (I/O1)
/D_ESDN: U1.16 (USBDM), U4.4 (I/O2)
/D_ESDP: U1.15 (USBDP), U4.6 (I/O1)
/MCU/CON_RX_PC_TX: J1.2, U1.1 (TXD)
/MCU/CON_TX_PC_RX: J1.1, U1.5 (RXD)
/VBUS: C3.1, P1.A4 (VBUS), P1.A9 (VBUS), P1.B4 (VBUS), P1.B9 (VBUS), U1.20 (VCC), U2.1 (VIN), U2.3 (EN), U4.5 (VBUS)
GND: C1.2, C3.2, C4.2, P1.A1 (GND), P1.A12 (GND), P1.B1 (GND), P1.B12 (GND), P1.S1 (SHIELD), R1.2, R2.2, U1.7 (GND), U1.18 (GND), U1.21 (GND), U2.2 (GND), U4.2 (GND), X1.L1.1, X1.L1.2
unnamed: D1.2 (A), R4.2
unnamed: D1.1 (K), U1.23 (GPIO0)
unnamed: D2.2 (A), R5.2
unnamed: D2.1 (K), U1.22 (GPIO1)
unnamed: P1.A5 (CC), R2.1
unnamed: P1.B5 (VCONN), R1.1
unnamed: C1.1, U1.17 (VCCD)

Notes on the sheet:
LINUX CONSOLE
Led wire connector for GND
150mm Picoblade assembled cable. Farnell ref 2671452

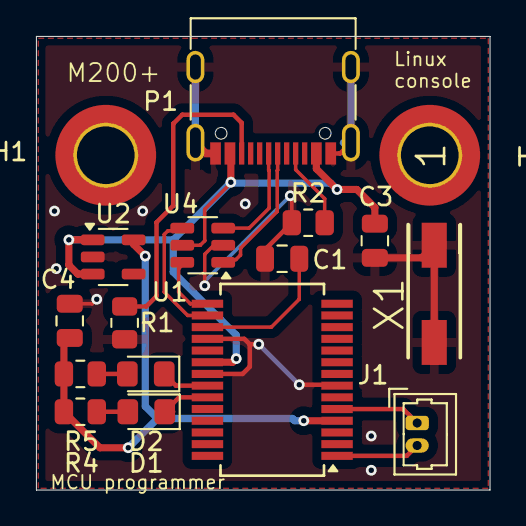
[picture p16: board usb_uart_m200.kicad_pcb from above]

Board: 2 copper layers, 25.2 x 25.2 mm, 17 parts (0 on the bottom side), 16 nets.

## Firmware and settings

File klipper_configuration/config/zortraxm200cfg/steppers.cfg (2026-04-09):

[stepper_x]
step_pin: X_STEP
dir_pin: !X_DIR
enable_pin: XYZE_ENABLE
# REV1
#endstop_pin: ^!X_MIN
# REV2
endstop_pin: ^X_MIN
#
position_endstop: 0
position_max: 200
homing_speed: 45
microsteps:16
rotation_distance:5.0

[stepper_y]
step_pin: Y_STEP
dir_pin: Y_DIR
enable_pin: XYZE_ENABLE
# REV1
#endstop_pin: ^!Y_MIN
# REV2 with optical stops
endstop_pin: ^Y_MIN
#
position_endstop: 0
position_max: 200
homing_speed: 45
microsteps:16
rotation_distance:5.0

# Check in console with: "STEPPER_BUZZ STEPPER=stepper_z" after moving the table to the middle.
[stepper_z]
step_pin: Z_STEP
dir_pin: !Z_DIR
enable_pin: XYZE_ENABLE
endstop_pin: Z_MAX
#endstop_pin: ^!Z_MIN_PROBE
#endstop_pin: probe:z_virtual_endstop
position_min: -2 # Give room for adjustments but you should set the bed to Z=0 and have some pressure on the adjustment screws
position_endstop: 185
position_max: 190
homing_speed: 16
second_homing_speed: 8
homing_positive_dir: true
microsteps: 8
rotation_distance: 32

[extruder]
step_pin: E0_STEP
dir_pin: E0_DIR
enable_pin: XYZE_ENABLE
microsteps:16
rotation_distance:3.33
nozzle_diameter: 0.400
filament_diameter: 1.750
heater_pin: HEAT_0
sensor_type: AD8495
adc_voltage: 3.0
#voltage_offset: 0.005
sensor_pin: TEMP_0
control: pid
max_power: 0.8
# Pid calibration to 260°C with fans at 0%
#pid_Kp: 24.937
#pid_Ki: 0.766
#pid_Kd: 202.925
# Pid calibration to 200°C with fans at 50%
pid_Kp=25.042
pid_Ki=0.755
pid_Kd=207.534
# Pid calibration to 200°C with fans at 100%
# Forget it
min_temp: 0
max_temp: 300
#min_extrude_temp: 0 ; Allow cold extrusion for testing
max_extrude_only_distance: 300
pressure_advance: 0.1

# If not, the pid calibration will fail
[verify_heater extruder]
max_error: 240
check_gain_time: 120

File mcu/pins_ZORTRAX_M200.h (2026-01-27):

/**
 * Marlin 3D Printer Firmware
 * Copyright (c) 2021 MarlinFirmware [https://github.com/MarlinFirmware/Marlin]
 *
 * Based on Sprinter and grbl.
 * Copyright (c) 2011 Camiel Gubbels / Erik van der Zalm
 *
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
 */
#pragma once

/**
 * Zortrax M200/M300 (STM32F103VCT6) board pin assignments
 */

#include "env_validate.h"

#define BOARD_INFO_NAME "Zortrax M200/M300"

//
// Stepper Motors
//

#define X_STEP_PIN          PB3   // X_STP_Pin
#define X_DIR_PIN           PD9   // X_DIR_Pin
#define X_ENABLE_PIN        PD14  // MOT_EN_Pin (shared)
#define X_MS1_PIN           PB10  // X_MS1_Pin
#define X_MS2_PIN           PB11  // X_MS2_Pin
#define X_MS3_PIN           PD8   // X_MS3_Pin

#define Y_STEP_PIN          PB4   // Y_STP_Pin
#define Y_DIR_PIN           PD13  // Y_DIR_Pin
#define Y_ENABLE_PIN        PD14  // MOT_EN_Pin (shared)
#define Y_MS1_PIN           PD10  // Y_MS1_Pin
#define Y_MS2_PIN           PD11  // Y_MS2_Pin
#define Y_MS3_PIN           PD12  // Y_MS3_Pin

#define Z_STEP_PIN          PB7   // Z_STP_Pin
#define Z_DIR_PIN           PC12  // Z_DIR_Pin
#define Z_ENABLE_PIN        PD14  // MOT_EN_Pin (shared)
#define Z_MS1_PIN           PA15  // Z_MS1_Pin
#define Z_MS2_PIN           PC10  // Z_MS2_Pin
#define Z_MS3_PIN           PC11  // Z_MS3_Pin

#define E0_STEP_PIN         PA0   // E_STP_Pin
#define E0_DIR_PIN          PD0   // E_DIR_Pin
#define E0_ENABLE_PIN       PD14  // MOT_EN_Pin (shared)

//
// Endstops
//
#define X_MIN_PIN           PE12   // X_ENDSTOP_Pin
#define Y_MIN_PIN           PC6   // Y_ENDSTOP_Pin
// #define Z_MIN_PIN           PE15  // Z_SENSOR_Pin
// #define Z_MAX_PIN           PA8   // Z_DOWN_ENDSTOP_Pin
#define Z_MIN_PROBE_PIN         PC7   // PLATFORM_ENDSTOP_Pin
// #define FILAMENT_RUNOUT_PIN PD15  // FILAMENT_ENDSTOP_Pin

//
// Heaters / Fans
//
#define HEATER_0_PIN        PC8   // HEATER_PWM_Pin
#define HEATER_BED_PIN      PC9   // PLATFORM_HEATER_Pin
#define FAN0_PIN            PE13  // FAN1_Pin
#define FAN1_PIN            PE14  // FAN2_Pin

//
// Temperature Sensors
//
#define TEMP_0_PIN          PB1   // EXT_TEMP_Pin (ADC1_CHANNEL_9)
#define TEMP_BED_PIN        PB0   // PLATFORM_TEMP_Pin (ADC1_CHANNEL_8)

//
// SD Card (SPI1)
//
#define SD_SS_PIN           PA4  // SD chip select
// #define SD_SCK_PIN          PA5
// #define SD_MISO_PIN         PA6
// #define SD_MOSI_PIN         PA7
// #define SD_DETECT_PIN       PB2

//
// Display (SSD1322 256x64 4bpp grayscale OLED, SPI2)
//
#define DOGLCD_CS           PB12   // Chip select for SSD1322
#define DOGLCD_A0           PB14   // Data/Command for SSD1322
#define DOGLCD_MOSI         PB15
#define DOGLCD_SCK          PB13

#define LCD_RESET_PIN       PE10
#define OLED_PWR            PE9    // PWR pin for SSD1322

#define FORCE_SOFT_SPI

//
// Buzzer
//
#define BEEPER_PIN          PC4   // BUZZER_Pin (for display beeper)

//
// Rotary Encoder
//
#define BTN_ENC             PC5   // Encoder click
#define BTN_EN1             PE7   // Encoder EN1
#define BTN_EN2             PE8   // Encoder EN2

//
// Case Light RGB LED Strip
//
#define LED_PIN_R           PD7   // R_LED_PIN
#define LED_PIN_G           PB5   // G_LED_PIN
#define LED_PIN_B           PD6   // B_LED_PIN

//
// Debug UART
//
#define SERIAL_TX_PIN       PA9   // DEBUG_UART_TX_Pin
#define SERIAL_RX_PIN       PA10  // DEBUG_UART_RX_Pin

// Enable OLED
#define BOARD_PREINIT() { \
  OUT_WRITE(OLED_PWR, HIGH); \
}

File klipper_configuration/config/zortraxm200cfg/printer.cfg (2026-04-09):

[printer]
kinematics: cartesian
max_velocity: 130
max_accel: 1100
max_z_velocity: 50
max_z_accel: 200
square_corner_velocity: 10.8

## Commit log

2025-10-24 Schematics of the uart board
    [usb_uart_m200.kicad_pcb, usb_uart_m200.kicad_sch]
2025-10-24 Fex files from the first dump on the board where the Wifi is on USB.
    The first fex is the good one with the proper LCD driver.
2025-11-19 Add MarlinConfigurations as a submodule
2025-11-19 Changed the rpanfili configuraiton to use the original MCU.
    [bed_mesh.cfg, beep.cfg, board_pins.cfg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]
2025-11-24 Some work on the driver.
2025-11-26 Compiling LCD driver
2025-12-10 Driver rework
    Initialisation bytes taken from the lcd.ko module binary content on the
    vendor linux plus some comparisons and fixes.
    [panel-mtf0397swi.c]
2025-12-10 A couple of name changes on the lcd driver.
2025-12-16 First draft of the MCU programmer / linux serial console.
    [usb_uart_m200.kicad_pcb, usb_uart_m200.kicad_sch]
2025-12-16 Routing
    Separated the uart from the FEL adapter board.
    Adds a led wire connector for the ground pin.
    [fel_mode_adapter.kicad_pcb, fel_mode_adapter.kicad_sch, usb_uart_m200.kicad_pcb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]
2026-01-08 Fix the board: add a regulator and farnelle references. Add a pull up on boot0
    [fel_mode_adapter.kicad_sch, usb_uart_m200.kicad_pcb, usb_uart_m200.kicad_sch]
2026-01-08 Fix on the usb uart power, it uses vbus.
    [usb_uart_m200.kicad_pcb, usb_uart_m200.kicad_sch]
2026-01-12 Add a picture showing how the EMMC boot0 partition was unbricked.
    A new EMMC was flashed using a chip programmer over USB and then
    soldered on the board.
    Not everything was clean owever, but booting, an image copy was dd on
    emmcblk2 from the booted linux.
2026-01-12 This is the binary image used to chainload u-bbot mainline from the old u-boot sunxi.
    dd this file to /dev/mmcblk2p5 to chainload u-boot.
2026-01-15 Mainline driver
2026-01-23 Removed the DEBUG header from the serial port board since the MCU needs a stlink total erase.
    Adds the screen capture of the configuration in Katapult menuconfig.
    [usb_uart_m200.kicad_pcb, usb_uart_m200.kicad_sch]
2026-01-23 Droping the vendor bootloader protocol investigation.
    It is so obfuscated and therefore we will use klipper, if you flash
    katapult there is no going back.
    And for your next printer, think about a Voron.
2026-01-25 Klipper configuration files
    [bed_mesh.cfg, beep.cfg, board_pins.cfg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]
2026-01-25 The Z Min pin is not the same on the plus version.
    [zortraxm200plus_mcu.cfg]
2026-01-25 Klipper configuration
    FANS, X, Y Extruder steppers, temperature sensors and RGB leds are
    working.
    [beep.cfg, board_pins.cfg, heater_bed.cfg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]
2026-01-26 Adding a BOM file for the extra stuff not soldered on the board.
2026-01-27 Test spazzimoto driver and try to mix it wih mine
    While the drivers are really close, and both work, using the spazzimoto
    parameters in mine gives a segfault.
    Seems that removing MIPI_DSI_MODE_VIDEO_BURST solves the shifted screen
    problem.
    [panel-mtf0397swi.c]
2026-01-27 Screnn oriantation documentation for KlipperScreen.
2026-01-27 Removed the SPAZZIMOTO_TIMINGS define, because it is not compatible.
    It is a driver or the other, but mixing them does not work.
    Sapzzimoto driver init sequence came from microtech and hence is not a
    guess work like here.
    [panel-mtf0397swi.c]
2026-01-27 This script is not needed anymore. The lcd driver works.
2026-01-28 Adding the firmware working with katapult
    Green light is katapult boot
    Blue light is klipper
2026-02-23 ZStop, Probe, Filament sensor, ZStepper
    My Z axis has a problem. Until I try on another printer, I do not know
    what is going on. I had to increase the values on the Z stepper compared
    to the theoretical 8mm/turn.
    The Zstop is at the botton, and the probe being the nozzle is at the top
    but the "probe" command looks for it on the bottom.
    [filament_sensor.cfg, probe.cfg, steppers.cfg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]
2026-02-26 Got the Z axis working with the optical sensor stop.
    The probe sensor is not good enough on the M200, it must be perfectly
    clean on bed leveling but we cannot expect to be clean all the time.
    [probe.cfg, steppers.cfg]
2026-03-04 The tepearatures and PID are configured.
    3V3 on the thermistors was causing problems, the software uses 5V by
    default.
    Ran the PID tests on the hardware.
    [heater_bed.cfg, steppers.cfg]
2026-03-04 Adds a GND test point to the FEL mode adapter.
    [fel_mode_adapter.kicad_pcb, fel_mode_adapter.kicad_sch]
2026-03-04 Lib files for the usb uart.
2026-03-07 Fixing speed on the extruder.
    It is diameter * Pi: I entered 9mm x Pi.
    It rotates more slowly.
    [steppers.cfg]
2026-03-08 adds Print-Tuning-Guide as submod + extruder qualibrated and fixes in macros
    [change_filament.cfg, interactive_pause.cfg, m300.cfg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]
2026-03-08 Fixing the Z axis rattling (after greasing and tightening things up)
    [printer.cfg, steppers.cfg]
2026-03-11 PID tuning with the fan on
    First tuning cube print with a prime line, ZABS, 260°C, fan at 40%, and
    bed at 55°C then 78°C with the regular M200 plus printing head.
    The Z acceleration was still aproble during print, it was not noticed
    during Z axis homing. It still does some noise during the print since
    acceleration and speed had to be decreased again.
    The 100% fan heater calibration would fail. So it is strugling at 50%
    and it is good enough at 40%.
    [printer.cfg, steppers.cfg]
2026-03-18 Adding the boot0 image, just as a safety.
    Boot0 is a protected sector, the only thing able to load the FEL monde
    on the Zortrax M200.
    If like me you end up destroying it, and having to program a new one
    using a MMC programmer and soldering the chip.
2026-03-18 Documenting my second failure with boot0
    I cofused Boot0 from the start with a separate parition, and I managed
    to destroy it a second time. And the soldering of the new chip half
    failed, leaving me only with Boot0.
    To my defense, this is not well documented. Like the secondary u-boot at
    0x12A6000
2026-03-18 Fixing a touchscreen issue
    The touchscreen driver was not packed during the Armbian image creation.
    So I added the instructions to build it on the target like the LCD
    driver.
2026-03-19 Bootenv to chainload uboot mainline from the stock u-boot
    However the chainloaded uboot won't have acess to the EMMC. It now has
    acess from FEL mode but not after chainload.
2026-03-26 Adding the plans of an A33 board as submodule.
2026-03-26 Freecad 1.1 drawing to mount a dragon burner on the Zortrax m200
    I have a printer without nozzle and another one with a cheap replacement
    nozzle. I will place a Rapido and a TZ6 on a dragon burner head.
    [dragonburnermountonM200_B.FCStd]
2026-03-26 Updating the dragon burner adapter
    [dragonburnermountonM200_B.FCStd]
2026-03-31 Adding a pocket for cables on the side. Changing the screws to 35mm for more rigidity.
    [dragonburnermountonM200_B.FCStd]
2026-03-31 Changed the dragon burner mount
    The last change did not work, because the screws crossed the same path.
    They could not fit together.
    I replaced the 6mm holes with a tiny hole to fit the hex key, and a
    pocket to insert a smaller 6mm flat head hex screw
    [dragonburnermountonM200_B.FCStd]
2026-03-31 Improvements for the dragon burner attachment.
    Removes a side of the mount to pass the cables. Increases slightly the
    pocket holes for the 3M 6mm screws.
    Add a washer project because the TZ-6 nozzle was wobling. His screws
    were pressing against the fan metal while not pressing on the plastic
    mount.
    [dragonburnermountonM200_B.FCStd, washerforTZ-6-V2.FCStd]
2026-04-05 Adds an extruder cover to fit the dragon burner mod wires if they are longer than needed.
    [extrudercoverbackwithmorespace.stl, washerforTZ-6-V2.FCStd]
2026-04-05 Some dev diary update
    Removing dangerous commands from the diary (who can brick the board).
2026-04-06 Cleanup and adding mecanical stuff
    Cleanup in the documentation.
    Adding the dragon bruner mount, a bl touch mount.
    [bltouchmount.FCStd, bltouchmount.stl, dragonburnermountonM200_B.stl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]
2026-04-09 Updates on the dragon burner adaptation.
    [bltouchmount.FCStd]
2026-04-09 Washers stl file for TZ-V6-2 hotend.
    Without them, the hotend is moving.
    [washerforTZ-6-V2.stl]
2026-04-09 Got the stepper Z configuraiton right.
    [steppers.cfg]

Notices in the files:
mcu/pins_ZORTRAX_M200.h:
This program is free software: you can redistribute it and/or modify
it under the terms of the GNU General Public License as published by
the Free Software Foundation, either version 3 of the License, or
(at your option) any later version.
